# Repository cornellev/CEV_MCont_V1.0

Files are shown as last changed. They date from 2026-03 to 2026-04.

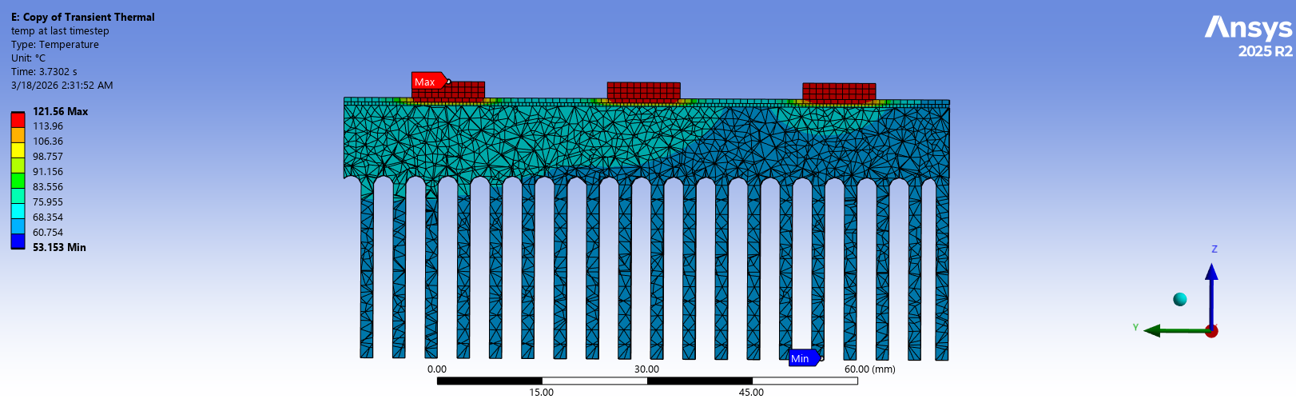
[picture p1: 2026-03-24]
analysis/Cross Section, large temp diff at TIM.png

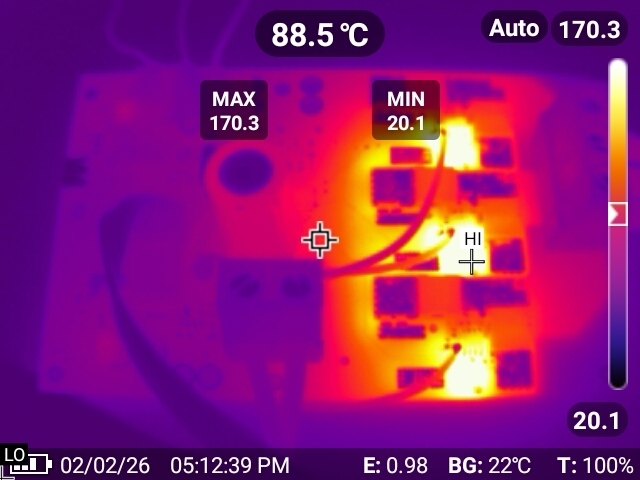
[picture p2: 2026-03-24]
analysis/Thermal 170 C.jpg

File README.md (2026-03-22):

# CEV Motor Controller V1.0

Open-source BLDC motor controller developed by **Cornell Electric Vehicles (CEV)** for the **Shell Eco-Marathon Urban Concept** competition.

This controller drives a **48 V battery electric drivetrain** using **sensored trapezoidal commutation** implemented on an **RP2040 microcontroller**. The design emphasizes:

* high efficiency
* high current capability
* deterministic switching behavior
* minimal firmware complexity

The controller supports:

* **48 V nominal battery systems**
* **60 V maximum bus voltage**
* **110 A continuous current (with heatsink)**
* **160 A peak current (~2 s)**

The firmware uses **RP2040 PIO state machines** to generate precise PWM and gate drive signals with nanosecond-scale deadtime control.

---

# Repository Structure

```
hardware/
    CEV_MCont_V1.0/
        PCB design files here

firmware/
    MCont_V1.0-main/
        pico project here

docs/
    design-decisions.md
    power-stage-design.md
    layout-lessons.md
    bringup.md
    firmware.md
```

---

# System Architecture

```
Throttle (analog pedal)
        │
        ▼
RP2040 Microcontroller
        │
        ├── PIO PWM generator
        ├── PIO gate-drive timing
        ├── Hall sensor processing
        └── V/Hz control algorithm
        │
        ▼
External Gate Drivers (UCC27301)
        │
        ▼
3-Phase MOSFET Inverter
        │
        ▼
BLDC Motor
```

Telemetry and throttle reporting are transmitted to the vehicle control system through **SPI** using a **digital isolator**.

---

# Key Specifications

| Parameter | Value |
| --- | --- |
| Bus voltage | 48 V nominal |
| Maximum bus voltage | 60 V |
| Continuous current  | ~110 A |
| Peak current | ~160 A |
| Switching frequency | 5 kHz |
| Deadtime | 256 ns |
| Gate drive voltage  | 15 V |

---

# Major Hardware Components

### Microcontroller

**RP2040**

Responsibilities:

* hall sensor decoding
* commutation logic
* speed estimation
* PWM duty control
* gate drive timing coordination

---

### Gate Drivers

**UCC27301**

Features:

* high peak drive current
* fast switching capability
* 15 V gate drive

Gate resistors:

| MOSFET | Gate resistor |
| --- | --- |
| Low side  | 1 Ω |
| High side | 4.02 Ω |

High-side resistors are intentionally larger to reduce dV/dt-induced shoot-through.

---

### MOSFETs

**NTBLS0D8N08XTXG**

Characteristics:

* 100 V VDS
* **0.79 mΩ RDS(on)**
* power package optimized for high current

These devices replaced earlier MOSFETs used in prior revisions.

---

# Motor Commutation

The controller uses **sensored six-step trapezoidal commutation**.

Three hall sensors embedded in the motor determine rotor position.

At any time:

* one phase is **PWM driven**
* one phase is **pulled to ground**
* one phase is **tristated**

This minimizes switching events while maintaining torque production.

---

# Firmware Highlights

The firmware leverages **RP2040 PIO** to ensure precise switching timing:

* PIO generates the PWM signal
* PIO generates gate drive outputs
* CPU performs commutation logic

This architecture allows deterministic switching and very low jitter.

---

# Deadtime Strategy

Deadtime is inserted only on the phase that switches between high-side and low-side conduction.

Deadtime is:

```
32 PIO cycles
≈256 ns
```

This prevents shoot-through while minimizing switching loss.

---

# Hall Sensor Interface

The hall sensors:

* operate at **5 V supply**
* use **open-drain outputs**

Pull-up resistors bring the logic level to **3.3 V** for the RP2040.

This allows safe level translation without additional hardware.

---

# Telemetry Interface

The controller reports throttle and telemetry over **SPI** to the central vehicle computer.

The SPI interface passes through a **digital isolator** for noise immunity and system safety.

---

# License

This project is released under the **MIT License**.

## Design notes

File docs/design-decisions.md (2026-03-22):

# Design Decisions — CEV_MCont_V1.0

This document explains the engineering decisions behind the design of **CEV_MCont_V1.0**, a BLDC motor controller developed by Cornell Electric Vehicles for the Shell Eco-Marathon Urban Concept competition.

The V1.0 design represents a major architectural shift from earlier revisions by replacing the integrated motor driver with a fully software-controlled architecture.

---

# System Design Goals

The motor controller was designed with the following goals:

* High efficiency
* High current capability
* Deterministic switching behavior
* Minimal switching losses
* Robust operation in an automotive environment
* Simple and transparent firmware

The system operates from a **48 V battery pack** with a maximum bus voltage of approximately **56 V**, and is designed for up to **60 V absolute maximum**.

---

# Removal of Integrated Gate Driver

Earlier revisions used the **DRV8353** integrated gate driver.

Although convenient, this architecture had several limitations:

* Gate driver located far from MOSFETs
* Limited gate drive strength
* Difficult debugging when driver faults occurred
* Reduced flexibility in switching timing

In V1.0 the DRV8353 was removed entirely.

Instead, the **RP2040 directly controls external gate drivers**, which significantly improves:

* switching performance
* layout flexibility
* debugging transparency
* firmware control of switching behavior

---

# Use of External Gate Drivers

The controller uses **UCC27301 gate drivers**.

Advantages:

* strong gate drive current capability
* simple interface
* excellent switching performance

Gate resistors are asymmetric:

| MOSFET | Gate Resistor |
| --- | --- |
| Low-side  | 1 Ω |
| High-side | 4.02 Ω |

The larger high-side resistor intentionally slows the rising edge of the switching node.

Benefits:

* reduces dV/dt induced turn-on
* prevents accidental low-side MOSFET activation
* improves switching stability

---

# RP2040 Control Architecture

The RP2040 was chosen for several reasons:

* dual-core architecture
* programmable I/O (PIO)
* deterministic timing capabilities
* inexpensive and widely available

The PIO hardware allows precise timing for:

* PWM generation
* deadtime insertion
* gate drive signal updates

This avoids timing jitter that would occur if switching signals were generated purely in software.

---

# Switching Frequency Selection

The inverter switching frequency is **5 kHz**.

This relatively low switching frequency was chosen intentionally.

Advantages:

* significantly lower switching loss
* reduced gate drive power
* reduced MOSFET heating
* sufficient acoustic performance for the application

Because the vehicle prioritizes efficiency over acoustic noise, the lower switching frequency is acceptable.

---

# Deadtime Implementation

Deadtime is implemented using an RP2040 PIO state machine.

Deadtime duration:

```id="deadtime_v1"
32 cycles
≈256 ns
```

Deadtime is applied **only to the phase that switches between MOSFETs**.

This minimizes conduction losses while preventing shoot-through.

---

# MOSFET Selection

V1.0 uses:

```id="mosfet_v1"
NTBLS0D8N08XTXG
```

Key characteristics:

* 100 V VDS rating
* extremely low **0.79 mΩ RDS(on)**
* package optimized for high-current power stages

These devices replaced earlier MOSFETs used in previous revisions.

The selection prioritized:

* minimal conduction loss
* strong thermal performance
* compact layout

---

# Hall Sensor Interface

The motor includes embedded hall sensors.

Characteristics:

* powered from **5 V**
* **open-drain outputs**

Because the outputs are open-drain, pull-up resistors bring the logic level to **3.3 V**, allowing safe direct connection to the RP2040.

This approach avoids the need for level-shifting hardware.

---

# SPI Telemetry Interface

The motor controller communicates with the vehicle's central computer using **SPI**.

SPI signals pass through a **digital isolator** to improve system robustness and reduce electrical noise coupling between subsystems.

The SPI interface is used for telemetry and throttle reporting.

---

# Control Strategy

The controller uses **sensored six-step trapezoidal commutation**.

Reasons for choosing this control method:

* simple implementation
* robust operation
* low computational cost
* excellent efficiency for the vehicle’s operating conditions

Field-oriented control was considered but was not necessary for this application.

---

# Thermal Design

Thermal simulations indicate the controller can support:

| Condition | Current |
| --- | --- |
| Continuous (with heatsink) | ~110 A  |
| Peak | ~160 A  |

Peak current can be sustained for approximately **2 seconds**.

These values depend strongly on airflow and heatsink performance.

---

# Summary

The V1.0 architecture prioritizes:

* switching efficiency
* deterministic timing
* layout-driven power performance
* firmware simplicity

This architecture proved significantly more robust than earlier integrated driver designs.

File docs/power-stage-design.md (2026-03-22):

# Power Stage Design — CEV_MCont_V1.0

This document describes the design and analysis of the inverter power stage.

The controller implements a **three-phase MOSFET inverter** designed for high efficiency and high current capability.

---

# Inverter Topology

The motor controller uses a standard **three-phase half-bridge inverter**.

Each phase consists of:

* one high-side MOSFET
* one low-side MOSFET

Total MOSFET count:

```id="fet_count"
6
```

---

# MOSFET Selection

The selected device:

```id="fet_type"
NTBLS0D8N08XTXG
```

Important parameters:

| Parameter  | Value |
| --- | --- |
| VDS rating | 100 V |
| RDS(on) | 0.79 mΩ |
| Package | High-current power package |

Low RDS(on) was the primary selection criterion to minimize conduction losses.

---

# Loss Model

MOSFET losses were modeled using the equation:

```id="loss_equation"
P_loss =
(I_rms^2 * R_DS_ON)
+ (V_bus * I_out / 2 * (t_on + t_off) * f_sw)
+ (V_bus^2 * C_oss * f_sw)
+ (V_g^2 * C_gs * f_sw)
```

Components:

| Term | Description |
| --- | --- |
| Conduction loss | resistive MOSFET loss |
| Switching loss | energy dissipated during transitions |
| Output capacitance loss | Coss charge/discharge |
| Gate drive loss | energy required to charge gate |

---

# Switching Performance

Measured switching characteristics:

| Parameter | Value |
| --- | --- |
| VGS plateau | ~100-150 ns |
| VDS rise/fall | ~200-300 ns |
| Switching frequency | 5 kHz |

Low switching frequency significantly reduces switching losses.

---

# Gate Drive Voltage

Gate drivers operate at:

```id="gate_voltage"
15 V
```

Higher gate voltage reduces MOSFET RDS(on), lowering conduction loss.

---

# Gate Drive Strategy

Gate resistors are asymmetric:

| MOSFET | Gate resistor |
| --- | --- |
| Low side  | 1 Ω |
| High side | 4.02 Ω |

The high-side resistor slows the switching edge slightly to prevent dV/dt-induced turn-on of the low-side MOSFET.

---

# Deadtime

Deadtime prevents shoot-through in each half bridge.

Deadtime duration:

```id="deadtime_value"
256 ns
```

Deadtime is inserted only when a phase transitions between high-side and low-side conduction.

---

# Bus Voltage

System bus parameters:

| Parameter | Value |
| --- | ----- |
| Nominal battery | 48 V  |
| Maximum battery | ~56 V |
| Design limit | 60 V  |

MOSFETs were selected with sufficient voltage margin for this operating range.

---

# Thermal Performance

Thermal simulations predict:

| Condition  | Current |
| --- | --- |
| Continuous | ~110 A  |
| Peak | ~160 A  |

These values assume the use of a heatsink.

Without a heatsink, current capability is significantly reduced.

---

# Switching Loss Optimization

Several design decisions were made to reduce switching losses:

* low switching frequency
* strong gate drive current
* minimized gate loop inductance
* high gate drive voltage

These improvements significantly reduce MOSFET heating.

---

# Summary

The power stage was optimized for:

* extremely low conduction losses
* controlled switching transitions
* high current capability

The resulting design provides efficient operation within the Eco-Marathon vehicle power system.

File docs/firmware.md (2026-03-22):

# Firmware Architecture

This document describes the firmware used in **CEV_MCont_V1.0**.

The firmware implements sensored trapezoidal motor control using the RP2040.

Major subsystems:

* commutation logic
* PIO gate drive state machine
* PIO PWM generator
* velocity estimation
* V/Hz speed controller

---

# Control Architecture

```
Hall sensors → commutation logic
Throttle → V/Hz controller → PWM duty
PWM + commutation → gate drive signals
```

The RP2040 performs the control computations while the **PIO state machines handle precise timing**.

---

# Commutation Logic

The hall sensors determine rotor position.

A three-bit state value is constructed:

```
state = ((a << 2) | (b << 1) | c) - 1
```

This state indexes a lookup table that determines which phase is:

* high
* low
* PWM driven

At each commutation step:

| Phase role | Behavior |
| --- | --- |
| PWM phase | PWM applied |
| Low phase | connected to ground |
| Floating phase | high-impedance |

---

# Gate Drive Encoding

Gate states are encoded into a **6-bit control word**:

```
[C_HIGH C_LOW B_HIGH B_LOW A_HIGH A_LOW]
```

Example control output:

```
0b0001PWM!PWM
```

This word is generated using bit-shift masks and lookup tables.

---

# Deadtime Generation

Deadtime is applied only to the phase that switches between MOSFETs.

Deadtime word example:

```
0b000100
```

Deadtime and control values are concatenated into a **12-bit value** sent to the PIO gate driver.

---

# Gate Drive PIO State Machine

The gate drive PIO performs the following sequence:

1. wait for FIFO value
2. output deadtime state
3. wait deadtime delay
4. output control state

Deadtime duration:

```
32 PIO cycles
≈256 ns
```

This ensures the control signal never updates without first inserting deadtime.

---

# PWM PIO State Machine

PWM generation is handled by a separate PIO state machine.

Parameters:

```
wrap = 255
switching frequency ≈ 5 kHz
```

Each cycle:

1. read duty cycle from FIFO
2. count down from wrap
3. toggle output when threshold reached

PIO interrupts trigger updates on **both rising and falling PWM edges**.

---

# Velocity Estimation

Velocity is determined from the time between hall sensor transitions.

Each transition represents:

```
1/24 mechanical revolution
```

because the motor has:

```
4 pole pairs
6 electrical states
```

Velocity equation:

```
raw_rpm = 2.5e6 / step_period
```

---

# Velocity Filtering

Velocity is filtered using a first-order low-pass filter:

```
alpha = timer_period / (TAU + timer_period)

motor_rpm = alpha * raw_rpm + (1 - alpha) * motor_rpm
```

This reduces measurement noise.

---

# V/Hz Speed Controller

Motor voltage is controlled using a **V/Hz strategy**.

The controller calculates a maximum duty cycle proportional to speed.

Throttle input selects a percentage of this maximum.

Benefits:

* constant magnetic flux
* stable torque production
* simple implementation

---

# Interrupt Architecture

The firmware uses both RP2040 cores.

```
Core 0
    PWM interrupt (highest priority)

Core 1
    Hall sensor interrupt

Main loop
    velocity update
```

This architecture reduced PWM jitter from **250 ns to 18 ns**.

---

# Debugging Lessons

Several issues were encountered during development:

### PWM Jitter

Cause:

interrupt contention.

Solution:

restructured interrupt priorities and moved velocity update to main loop.

---

### Shoot-Through

Cause:

incorrect deadtime logic.

Solution:

deadtime applied only to phases that switch.

---

### Hall Sensor Jitter

Observed hardware jitter was filtered in software by preventing reverse commutation.

---

# Summary

Using RP2040 PIO allows:

* deterministic switching
* precise deadtime control
* minimal CPU load

This architecture enables a simple and reliable BLDC controller.

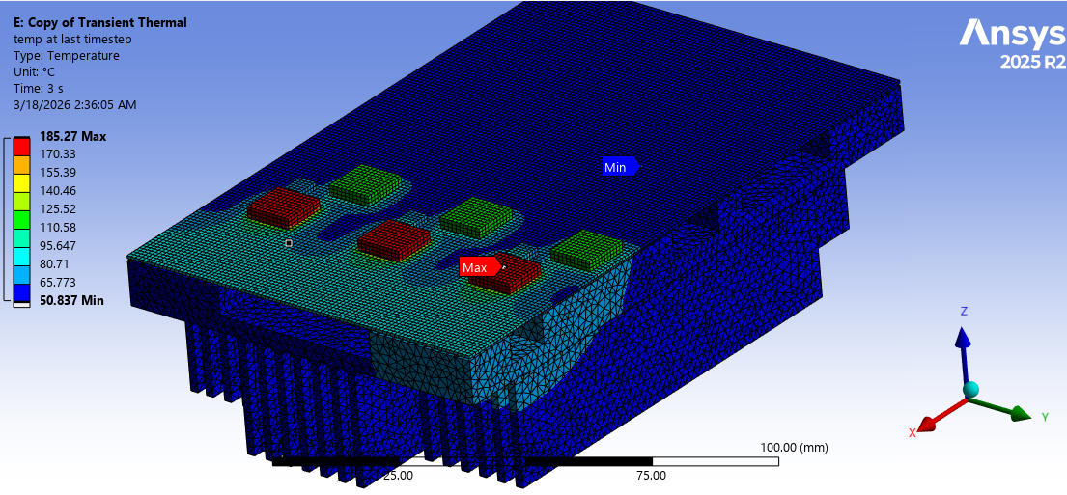
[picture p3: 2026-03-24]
analysis/160 A 3 sec pulse.png

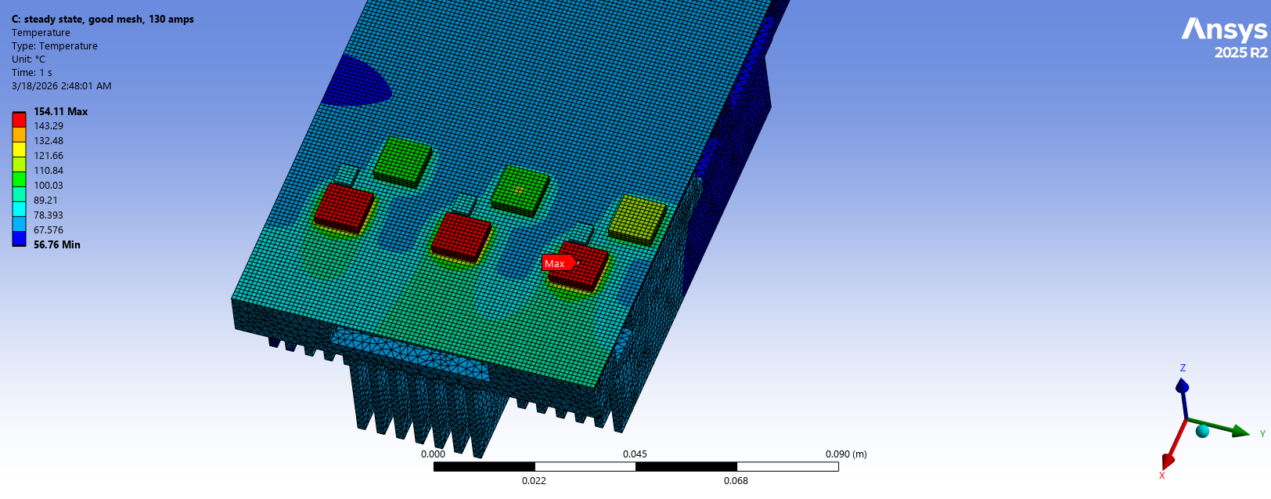
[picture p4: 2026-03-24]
analysis/Steady State 130 A.png

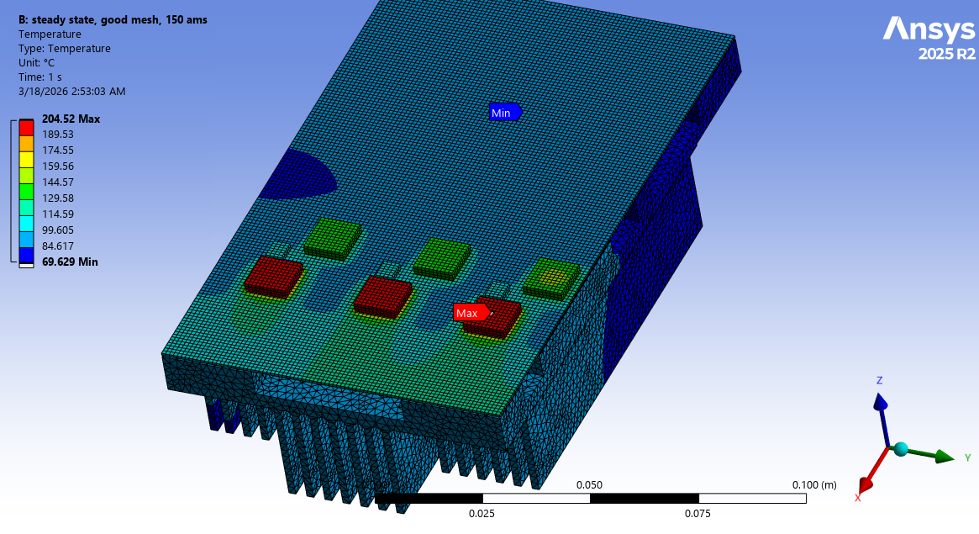
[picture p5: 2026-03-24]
analysis/Steady State 150 A 205 C.png

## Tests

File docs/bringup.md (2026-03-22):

# Bringup Procedure — CEV_MCont_V1.0

This document describes the recommended procedure for bringing up the motor controller safely.

---

# 1. Visual Inspection

Before powering the board:

* inspect for solder bridges
* verify MOSFET orientation
* verify gate driver orientation
* inspect power connectors

---

# 2. Resistance Checks

Using a multimeter:

Check resistance between:

* VBUS and GND
* phase outputs and ground

There should be **no short circuits**.

---

# 3. Power Logic Rails

Power the logic system first.

Verify:

| Rail  | Expected Voltage |
| ----- | --- |
| 3.3 V | RP2040 supply |
| 5 V | hall sensor supply |
| 15 V  | gate driver supply |

---

# 4. Flash Firmware

Connect USB to the RP2040.

Flash firmware using the RP2040 UF2 bootloader.

Confirm the firmware boots successfully.

---

# 5. Verify Hall Inputs

Rotate the motor by hand and verify that hall signals toggle.

Confirm that rotor state changes are detected by firmware.

---

# 6. Power the Bus

Apply bus voltage from the battery.

Ensure the battery voltage is within the safe operating range:

```id="bus_range"
0–60 V
```

---

# 7. Verify Gate Signals

Using an oscilloscope:

Check gate drive outputs.

Verify:

* PWM switching
* proper deadtime
* no overlapping gate signals

---

# 8. Initial Motor Test

Connect the motor and slowly apply throttle.

Verify:

* correct rotation direction
* smooth commutation
* stable PWM behavior

---

# 9. Monitor Temperature

During early testing:

* monitor MOSFET temperature
* ensure adequate cooling

High currents should not be applied until thermal performance is verified.

---

# Summary

Following this procedure helps ensure safe first operation of the motor controller and reduces the risk of damaging components.

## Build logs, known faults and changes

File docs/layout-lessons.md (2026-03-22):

# PCB Layout Lessons — CEV_MCont_V1.0

Power electronics performance is heavily influenced by PCB layout.

Many of the improvements in V1.0 were driven by lessons learned from earlier controller revisions.

---

# Minimize Switching Loop Area

The highest current loop in the system is:

```id="switch_loop"
DC link capacitor
→ high-side MOSFET
→ phase node
→ low-side MOSFET
→ ground
```

This loop must be made as small as possible.

Reducing this loop area:

* lowers switching inductance
* reduces voltage spikes
* improves EMI performance

---

# Gate Driver Placement

Gate drivers should be placed **as close as possible to the MOSFET gates**.

Long gate traces introduce:

* inductance
* ringing
* slower switching transitions

Using external drivers allowed them to be positioned directly next to the MOSFETs.

---

# Gate Drive Return Path

Gate signals must have a tight return path.

Key rule:

* gate trace and return path should run directly above a solid ground plane.

Interruptions in the ground plane increase loop inductance and degrade switching performance.

---

# Kelvin Source Routing

For accurate gate drive reference, the source connection of each MOSFET should be routed using **Kelvin connections** where possible.

This reduces the effect of source inductance during switching.

---

# Ground Plane Strategy

A continuous ground plane should be maintained under:

* gate drivers
* microcontroller
* signal traces

This provides a low-impedance return path for switching currents.

---

# Separate Power and Logic Domains

High current power paths should be separated from sensitive logic circuitry.

Key strategies:

* dedicated ground returns
* short current paths
* careful routing of high di/dt nodes

---

# DC Link Capacitor Placement

The DC link capacitors should be placed directly across the power stage.

Poor capacitor placement increases:

* switching loop inductance
* voltage overshoot
* capacitor heating

---

# Thermal Copper

High-current regions require large copper pours to distribute heat.

Additional copper layers were added in V1.0 to improve thermal performance.

---

# Summary

Careful PCB layout is essential for reliable high-current power electronics.

Many improvements in V1.0 resulted directly from optimizing the current loops and gate drive layout.

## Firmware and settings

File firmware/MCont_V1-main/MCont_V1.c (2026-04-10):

#include <stdio.h>
#include <string.h>
#include <math.h>
#include <stdbool.h>
#include "pico/stdlib.h"
#include "pico/multicore.h"
#include "hardware/pio.h"
#include "hardware/adc.h"
#include "hardware/clocks.h"
#include "pwm.pio.h"
#include "gate_drive.pio.h"
#include "pico/time.h"
#include "hardware/spi.h"
#include "hardware/dma.h"
#include "hardware/irq.h"
#include "hardware/structs/io_bank0.h"

// ====================================================================
//
//     ↓ telemetry code ↓
//    (thank you daniel h sorokin my goat)
//
// ====================================================================

// SPI configuration for telemetry
#define SPI_PORT spi0
#define PIN_RX   8
#define PIN_CS   9
#define PIN_SCK  6
#define PIN_TX   7

#define FLAG_BYTE 0x7E
#define TELEMETRY_PAYLOAD_LEN (4u + 4u + 4u)   // ts_us + motor_rpm + throttle
#define TELEMETRY_FRAME_MAX_BYTES ( \
    ( ( ( ((TELEMETRY_PAYLOAD_LEN + 4u) * 8u * 6u + 4u) / 5u ) + 16u ) + 7u ) / 8u \
)

static int spi_tx_dma_chan = -1;
static uint8_t payload_buf[TELEMETRY_PAYLOAD_LEN];
static uint8_t frame_buf[TELEMETRY_FRAME_MAX_BYTES];

typedef struct __attribute__((packed)) {
    uint32_t ts_us;
    float motor_rpm;
    float throttle;
} telemetry_t;

volatile telemetry_t latest_telem = {0};

static inline void set_gpio_hi_z(uint pin) {
    gpio_set_function(pin, GPIO_FUNC_SIO);
    gpio_set_dir(pin, GPIO_IN);
    gpio_disable_pulls(pin);
}

static inline void pack_u32_le(uint8_t *dst, uint32_t x) {
    dst[0] = (uint8_t)(x & 0xFF);
    dst[1] = (uint8_t)((x >> 8) & 0xFF);
    dst[2] = (uint8_t)((x >> 16) & 0xFF);
    dst[3] = (uint8_t)((x >> 24) & 0xFF);
}

static inline void pack_f32_le(uint8_t *dst, float f) {
    memcpy(dst, &f, 4);
}

static uint32_t crc32_ieee(const uint8_t *data, size_t length) {
    uint32_t crc = 0xFFFFFFFFu;
    for (size_t i = 0; i < length; i++) {
        crc ^= data[i];
        for (int j = 0; j < 8; j++) {
            if (crc & 1u)
                crc = (crc >> 1) ^ 0xEDB88320u;
            else
                crc >>= 1;
        }
    }
    return ~crc;
}

static inline bool push_bit(uint8_t *out, uint32_t *bitpos, uint8_t bit) {
    uint32_t byte_i = (*bitpos) >> 3;
    uint32_t bit_i  = (*bitpos) & 7;
    if (byte_i >= TELEMETRY_FRAME_MAX_BYTES) return false;
    if (bit) out[byte_i] |= (uint8_t)(1u << (7 - bit_i));
    (*bitpos)++;
    return true;
}

static bool bit_stuff(const uint8_t *in, size_t len, uint8_t *out, uint32_t *bitpos) {
    int ones = 0;

    for (size_t i = 0; i < len; i++) {
        for (int b = 7; b >= 0; b--) {
            uint8_t bit = (in[i] >> b) & 1u;
            if (!push_bit(out, bitpos, bit)) return false;

            if (bit) ones++;
            else     ones = 0;

            if (ones == 5) {
                if (!push_bit(out, bitpos, 0)) return false;
                ones = 0;
            }
        }
    }
    return true;
}

static void build_payload(uint8_t *payload) {
    telemetry_t snap = latest_telem;
    pack_u32_le(&payload[0], snap.ts_us);
    pack_f32_le(&payload[4], snap.motor_rpm / 5.0f); // divide by 5 for gearbox
    pack_f32_le(&payload[8], snap.throttle);
}

// START + STUFF(payload|crc) + END
static uint32_t build_frame(uint8_t *out, const uint8_t *payload) {
    uint8_t tmp[TELEMETRY_PAYLOAD_LEN + 4u];
    memcpy(tmp, payload, TELEMETRY_PAYLOAD_LEN);

    uint32_t crc = crc32_ieee(payload, TELEMETRY_PAYLOAD_LEN);
    pack_u32_le(&tmp[TELEMETRY_PAYLOAD_LEN], crc);

    memset(out, 0, TELEMETRY_FRAME_MAX_BYTES);
    out[0] = FLAG_BYTE;

    uint32_t bitpos = 8; // after first flag byte
    if (!bit_stuff(tmp, sizeof(tmp), out, &bitpos)) return 0;

    uint32_t bytes = (bitpos + 7u) >> 3;
    if (bytes + 1u > TELEMETRY_FRAME_MAX_BYTES) return 0;

    out[bytes] = FLAG_BYTE;
    return bytes + 1u;
}

static void configure_spi_dma(void) {
    spi_tx_dma_chan = dma_claim_unused_channel(true);
    dma_channel_config c = dma_channel_get_default_config(spi_tx_dma_chan);
    channel_config_set_transfer_data_size(&c, DMA_SIZE_8);
    channel_config_set_read_increment(&c, true);
    channel_config_set_write_increment(&c, false);
    channel_config_set_dreq(&c, DREQ_SPI0_TX);

    dma_channel_configure(
        spi_tx_dma_chan,
        &c,
        &spi_get_hw(SPI_PORT)->dr,
        frame_buf,
        0,
        false
    );
}

static void answer_spi(void) {
    if (spi_tx_dma_chan >= 0) dma_channel_abort(spi_tx_dma_chan);

    gpio_set_function(PIN_TX, GPIO_FUNC_SPI);

    spi_get_hw(SPI_PORT)->icr = SPI_SSPICR_RORIC_BITS;
    while (spi_is_readable(SPI_PORT))
        (void)spi_get_hw(SPI_PORT)->dr;

    build_payload(payload_buf);
    uint32_t frame_len = build_frame(frame_buf, payload_buf);
    if (frame_len == 0) {
        set_gpio_hi_z(PIN_TX);
        return;
    }

    dma_channel_set_read_addr(spi_tx_dma_chan, frame_buf, false);
    dma_channel_set_trans_count(spi_tx_dma_chan, frame_len, true);
}

static void configure_spi_slave(void) {
    spi_init(SPI_PORT, 1000 * 1000);
    spi_set_slave(SPI_PORT, true);
    spi_set_format(SPI_PORT, 8, SPI_CPOL_0, SPI_CPHA_1, false);

    gpio_set_function(PIN_RX, GPIO_FUNC_SPI);
    gpio_set_function(PIN_SCK, GPIO_FUNC_SPI);
    gpio_set_function(PIN_TX, GPIO_FUNC_SPI);
    set_gpio_hi_z(PIN_TX);

    gpio_init(PIN_CS);
    gpio_set_dir(PIN_CS, GPIO_IN);
    gpio_disable_pulls(PIN_CS);
}

static void spi_irq_handler(uint gpio, uint32_t events) {
    if (events & GPIO_IRQ_EDGE_FALL) {
        if (spi_tx_dma_chan >= 0) { dma_channel_abort(spi_tx_dma_chan); }
        set_gpio_hi_z(PIN_TX);
    } else if (events & GPIO_IRQ_EDGE_RISE) {
        answer_spi();
    }
}

void core1_entry() {    
    configure_spi_slave();

    irq_set_enabled(IO_IRQ_BANK0, true);
    gpio_set_irq_enabled_with_callback(
        PIN_CS, 
        GPIO_IRQ_EDGE_FALL | GPIO_IRQ_EDGE_RISE, 
        true, 
        &spi_irq_handler
    );

    configure_spi_dma();
    
    while (true) {
        tight_loop_contents();
    }
}

// ====================================================================
//
//     ↓ motor control code ↓
//    (keeping all the telemetry-related code above this line, 
//     except initialization in main() and updating the telemetry_t struct)
//
// ====================================================================

#define OUT_PINS 10
#define PWM_PIN 16
#define LED 17
#define THROTTLE_ADC 26

// the rotor position as defined by hall input values. 
// note that this value does not change incrementally as the motor moves!
volatile int state;

#define TAU 1e6 // time constant in us for low-pass filter
const uint32_t timer_us = 100 * 1000; // 100ms update velocity without hall trigger

// controls, velocity feedback, and volts per hertz values
volatile int dir = 1; // Car dir = 1, dyno dir = 1
volatile uint32_t prev_control = 0b000000;
volatile float motor_rpm = 0.0f;
const float MAX_VOLTAGE_AT_STALL = 4.0f;
const float RATED_MOTOR_VOLTAGE = 48.0f;
const float RATED_MOTOR_RPM = 3000.0f;
// const float RATED_MOTOR_VOLTAGE = 31.0f;
// const float RATED_MOTOR_RPM = 31.0f * (3000.0f / 48.0f);
const float MAX_DUTY_AT_STALL = MAX_VOLTAGE_AT_STALL / RATED_MOTOR_VOLTAGE;

#define MIN_RPM 25.0f
#define WRAPVAL 255

// if the motor is stationary, then the interrupt needs to be called
// periodically to avoid the interrupt from never being called
// and the motor_rpm from never being updated
struct repeating_timer timer;

// time of last irq
volatile uint32_t irq_prev_time = 0;

// commutation table
const uint8_t shift[2][6][3] = {
    { // clockwise
        {4,3,2},
        {2,1,0},
        {4,1,0},
        {0,5,4},
        {0,3,2},
        {2,5,4},
    },
    { // counterclockwise
        {2,5,4},
        {0,3,2},
        {0,5,4},
        {4,1,0},
        {2,1,0},
        {4,3,2},
    }
};

const uint8_t next[2][6] = { 
    { 4, 2, 0, 5, 3, 1 }, // clockwise
    { 2, 5, 1, 4, 0, 3 }  // counterclockwise
};

// PWM PIO state machine
PIO pwm_pio = pio0;
int pwm_sm = 0;

// GATE DRIVE PIO state machine
PIO gd_pio = pio1;
int gd_sm = 1;

// hall inputs
#define NUM_INPUTS 3
const uint input_pins[NUM_INPUTS] = {20, 19, 18};

#define abs(a) ((a>0) ? a:-a)

float constrainf(float x, float min, float max) {
    if (x < min) { return min; }
    if (x > max) { return max; }
    return x;
}

int adc_deadzone(int adc_value)
{
    const int DEADZONE = 100; // adc units

    if (adc_value < DEADZONE)
        return 0;
    if (adc_value > 4095 - DEADZONE)
        return 4095;
    adc_value = (adc_value - DEADZONE) * 4095 / (4095 - DEADZONE);
    return adc_value;
}

// Write `period` to the input shift register
void pio_pwm_set_period(PIO pio, uint sm, uint32_t period) {
    pio_sm_set_enabled(pio, sm, false);
    pio_sm_put_blocking(pio, sm, period);
    pio_sm_exec(pio, sm, pio_encode_pull(false, false));
    pio_sm_exec(pio, sm, pio_encode_out(pio_isr, 32));
    pio_sm_set_enabled(pio, sm, true);
}

// Write `level` to TX FIFO. State machine will copy this into X.
void pio_pwm_set_level(PIO pio, uint sm, uint32_t level) {
    pio->txf[sm] = level;
}

// Update values to drive the phases.
void update_control() {
    int pwm = gpio_get(PWM_PIN); 
    uint32_t control = 0b000000 | (1 << shift[dir][state][0]) | (pwm << shift[dir][state][1]) | (!pwm << shift[dir][state][2]); 

    // Only use deadtime for switching phase; i.e. the grounded phase remains grounded. 
    // uint32_t deadtime = 0b000000 | (1 << shift[dir][state][0]) ; 
    // uint32_t deadtime = (control == prev_control) ? control : 0b000000 | (1 << shift[dir][state][0]); 

    int deadtime_a;
    int deadtime_b; 
    int deadtime_c;

    if ((control & 0b110000) == (prev_control & 0b110000)) {
        deadtime_a = (control & 0b110000);
    } else {
        deadtime_a = 0b000000;
    }

    if ((control & 0b001100) == (prev_control & 0b001100)) {
        deadtime_b = (control & 0b001100);
    } else {
        deadtime_b = 0b000000;
    }

    if ((control & 0b000011) == (prev_control & 0b000011)) {
        deadtime_c = (control & 0b000011);
    } else {
        deadtime_c = 0b000000;
    }

    uint32_t deadtime = deadtime_a | deadtime_b | deadtime_c ;
    
    uint32_t data = (control << 6) | deadtime;
    pio_sm_put_blocking(gd_pio, gd_sm, data);
    prev_control = control;
}

void irq_handler(uint gpio, uint32_t events) {
    // Update rotor position & gate outputs.
    int a = gpio_get(input_pins[0]);
    int b = gpio_get(input_pins[1]);
    int c = gpio_get(input_pins[2]);
    if ((((a << 2) | (b << 1) | (c)) - 1) != next[dir][state]) { return; }
    state = ((a << 2) | (b << 1) | (c)) - 1;
    update_control();

    // Velocity feedback
    int irq_current_time = time_us_32();

    // time between steps in microseconds
    float step_period = (float)(irq_current_time - irq_prev_time);
    if (step_period <= 600.0f) { // invalid period, ignore
        return;
    }

    irq_prev_time = irq_current_time;

    // step/us * 1 elec. rev/6 steps * 1 mech. rev/4 elec. rev * 1e6 us/s * 60 s/min
    // = 2.5e6 rpm
    float raw_rpm = 2.5e6f / step_period; 

    // low-pass filter
    float alpha = step_period / (TAU + step_period);
    motor_rpm = alpha * raw_rpm + (1.0f - alpha) * motor_rpm;
}

// Update controls on rising & falling edges of PWM signal. 
void pwm_irq0() {
    pio_interrupt_clear(pwm_pio, 0);
    update_control();
}

int main() {
    // Overclocking, be aware that changing the system clock affects the switching dead time!
    set_sys_clock_khz(250000, true) ;
    stdio_init_all();
    multicore_launch_core1(core1_entry); 

    // Highest priority assigned to PIO PWM interrupt
    irq_set_priority(PIO0_IRQ_0, 0);
    irq_set_enabled(PIO0_IRQ_0, true);

    // Second priority assigned to GPIO interrupts for hall sensors    
    irq_set_priority(IO_IRQ_BANK0, 1);
    irq_set_enabled(IO_IRQ_BANK0, true);
    
    // Status LED
    gpio_init(LED);
    gpio_set_dir(LED, GPIO_OUT);
    gpio_put(LED, 1);

    // PWM PIO state machine
    uint pwm_offset = pio_add_program(pwm_pio, &pwm_program);    
    pwm_program_init(pwm_pio, pwm_sm, pwm_offset, PWM_PIN);
  
    irq_set_exclusive_handler(PIO0_IRQ_0, pwm_irq0);
    irq_set_enabled(PIO0_IRQ_0, true);
    pio_set_irq0_source_enabled(pwm_pio, pis_interrupt0, true);

    pio_pwm_set_period(pwm_pio, pwm_sm, WRAPVAL);
    pio_pwm_set_level(pwm_pio, pwm_sm, 0);

    // GATE DRIVE PIO state machine
    uint gd_offset = pio_add_program(gd_pio, &gate_drive_program);
    gate_drive_program_init(gd_pio, gd_sm, gd_offset, OUT_PINS);
    pio_sm_set_enabled(gd_pio, gd_sm, true);
    
    // configure adc for throttle input
    gpio_init(THROTTLE_ADC);
    gpio_set_dir(THROTTLE_ADC, GPIO_IN);
    adc_init();
    adc_gpio_init(THROTTLE_ADC);
    adc_select_input(0);

    // hall effect sensors
    gpio_set_irq_enabled_with_callback(
        input_pins[0], 
        GPIO_IRQ_EDGE_FALL | GPIO_IRQ_EDGE_RISE, 
        true, 
        &irq_handler
    );

    for (int i = 0; i < NUM_INPUTS; i++)
    {
        gpio_init(input_pins[i]);
        gpio_set_dir(input_pins[i], GPIO_IN);
        gpio_pull_up(input_pins[i]);
        gpio_set_irq_enabled(
            input_pins[i], 
            GPIO_IRQ_EDGE_RISE | GPIO_IRQ_EDGE_FALL, 
            true
        );
    }  
    int a = gpio_get(input_pins[0]);
    int b = gpio_get(input_pins[1]);
    int c = gpio_get(input_pins[2]);
    state = ((a << 2) | (b << 1) | (c)) - 1;

    uint32_t timer_current_time = time_us_32();

    while (true)
    {
        
        if (time_us_32() - irq_prev_time > timer_us) {

            // Timeout for hall input jitter filter.
            int a = gpio_get(input_pins[0]);
            int b = gpio_get(input_pins[1]);
            int c = gpio_get(input_pins[2]);
            if (state != ((a << 2) | (b << 1) | (c)) - 1) {
                state = ((a << 2) | (b << 1) | (c)) - 1;
                update_control();
            }

            // no velocity on boot
            if (irq_prev_time == 0) {
                motor_rpm = 0.0f;
            }

            timer_current_time = time_us_32();
            float timer_period = (float)(timer_current_time - irq_prev_time);
            
            // low-pass filter
            float raw_rpm = 2.5e6f / timer_period; 
            float alpha = timer_period / (TAU + timer_period);
            motor_rpm = alpha * raw_rpm + (1.0f - alpha) * motor_rpm;
            
            // minimum measurable rpm is 25 rpm
            if (motor_rpm < MIN_RPM)
                motor_rpm = 0.0f;
        }

        float throttle = (float) adc_deadzone(adc_read()) / 4095.0f;
        float max_duty = constrainf(motor_rpm / RATED_MOTOR_RPM + MAX_DUTY_AT_STALL, 0.0f, 1.0f);
        float duty = constrainf(throttle * max_duty, 0.0f, 1.0f);
        pio_pwm_set_level(pwm_pio, pwm_sm, (int)(duty * WRAPVAL));

        latest_telem.ts_us = time_us_32();
        latest_telem.motor_rpm = motor_rpm;
        latest_telem.throttle = throttle;
    }
}
